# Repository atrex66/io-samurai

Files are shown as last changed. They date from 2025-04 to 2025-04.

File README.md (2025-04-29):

# io-samurai
An open-source, budget-friendly CNC Input Output interface for LinuxCNC, 16 inputs (20–50 V), 8 high-current outputs (50 V, 500 mA Max), and single analog input (0–3.3 V). Supports W5100S-EVB-Pico module. Further support W5500-lite + pico or pico2

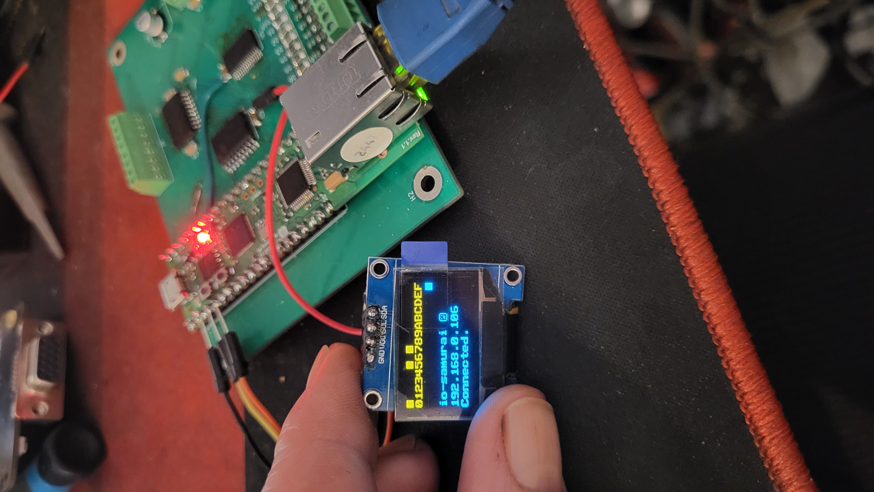
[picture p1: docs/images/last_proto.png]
io-samurai PCB


## Features
- **High-Speed Interface**: W5100S-evb-pico Ethernet. https://docs.wiznet.io/Product/iEthernet/W5100S/w5100s-evb-pico
- **Inputs**: 16 channels (MCP23017, I2C), 20–50 V, with 10 kΩ/1.5 kΩ divider and 3.6 V Zener protection.
- **Outputs**: 8 channels (TD62783 Darlington driver, MCP23008-controlled), 50 V, 500 mA/channel.
- **Analog Inputs**: 1 channels (GP26), 12-bit, ~10 kΩ potentiometer, 100 nF filtering.
- **Display**: Optional SH1106 OLED (128x64) for I/O status and IP address (not required for operation).
- **Software**:
  - LinuxCNC HAL driver, with safety functions (timeout, data checks).
  - Python library for automation/remote I/O.
  - Further Mach3 driver development.
- **Hardware Support**: W5100S-EVB-Pico.
- **Open-Source**: All code, PCB production files, and docs under MIT License.

## Support
- **Notes**: If you want to buy ready to go io-samurai send message to me for options.
- **Patreon**: Join our community at [patreon](https://www.patreon.com/c/user?u=43314769).

## License
This project is licensed under the MIT License. See [LICENSE](LICENSE).
The `ioLibrary_Driver` in `firmware/pico/ioLibrary_Driver.zip` is licensed under the MIT License by Wiznet. See [firmware/pico/ioLibrary_Driver.zip/LICENSE.txt](firmware/pico/ioLibrary_Driver.zip/LICENSE.txt).

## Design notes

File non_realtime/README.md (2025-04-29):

# io-samurai C++ Library

The `io-samurai` library is a C++ implementation for communicating with an IO Samurai device over UDP. It is derived from a LinuxCNC HAL driver and provides a simple interface to control digital outputs, read digital inputs, and process analog inputs. The library is designed for POSIX-compliant systems (e.g., Linux) and uses standard C++11 features.

## Features
- Initialize communication with an IO Samurai device using an IP address and port.
- Set and reset digital outputs (8 outputs, indexed 0–7).
- Read digital inputs (16 inputs, indexed 0–15).
- Read analog input (scaled to a user-defined range, with optional low-pass filter and rounding).
- Control OLED display state (on/off).
- Check connection status.
- Perform UDP send/receive operations in a single `update` call.

## Requirements
- **Compiler**: `g++` (GCC 4.8 or later, supporting C++11).
- **Operating System**: POSIX-compliant system (e.g., Linux, macOS). Windows is not supported without modifications.
- **Libraries**: Standard C++ Library and POSIX socket APIs (included in `libc` on Linux).
- **Jump Table**: A 256-byte checksum lookup table (`jump_table`) is required, provided via a symbolic link to `../firmware/w5100s-evb-pico/inc/jump_table.h`.

## Installation
1. **Clone or Download**: Obtain the source files:
   - `io-samurai.h`
   - `io-samurai.cpp` 
   - `jump_table.h`  (symbolic link, precreated, relative link to the firmware jump_table)
   - `usage_example.cpp` (example usage)

2. **Install Dependencies** (on Ubuntu/Debian):
   ```
   bash
   sudo apt update
   sudo apt install g++ libc6-dev
   ```

## Compilation
Compile the library and example using `g++`:

```
bash
g++ -std=c++11 -o io_samurai io-samurai.cpp main.cpp
```

**Flags**:
- `-std=c++11`: Enables C++11 features.
- `-o io_samurai`: Specifies the output executable name.

If the `jump_table` implementation is in a separate object file (e.g., `jump_table.o`):
```
bash
g++ -std=c++11 -o io_samurai io-samurai.cpp main.cpp jump_table.o
```

Run the program:
```
bash
./io_samurai
```

## Usage
The `io-samurai` class provides a straightforward API for interacting with the device. Below is an example program (`main.cpp`):

```
cpp
#include "io-samurai.h"
#include <iostream>
#include <chrono>
#include <thread>

int main() {
    io-samurai io;

    // Initialize with IP and port
    if (!io.init("192.168.1.100", 8080)) {
        std::cerr << "Initialization failed" << std::endl;
        return 1;
    }

    // Set analog range (e.g., 0 to 10 volts)
    io.set_analog_range(0.0f, 10.0f);
    io.set_analog_lowpass(true);  // Enable low-pass filter
    io.set_analog_rounding(true); // Enable rounding
    io.set_oled_off(false);       // Keep OLED on

    // Main loop
    while (true) {
        // Set outputs
        io.set_output(0, true);  // Set output 0
        io.set_output(1, false); // Clear output 1

        // Perform communication
        io.update();

        // Read inputs
        for (int i = 0; i < 16; i++) {
            std::cout << "Input " << i << ": " << io.get_input(i) << std::endl;
        }

        // Read analog input
        std::cout << "Analog In: " << io.get_analog_in() << std::endl;
        std::cout << "Analog In (s32): " << io.get_analog_in_s32() << std::endl;
        std::cout << "Connected: " << io.is_connected() << std::endl;

        // Sleep for 1 ms
        std::this_thread::sleep_for(std::chrono::milliseconds(1));
    }

    return 0;
}
```

### API Overview
- **Constructor/Destructor**:
  - `io-samurai()`: Initializes the object.
  - `~io-samurai()`: Closes the socket.

- **Initialization**:
  - `bool init(const std::string& ip_address, int port)`: Sets up the UDP socket with the given IP and port. Returns `true` on success.

- **Output Control**:
  - `void set_output(int index, bool value)`: Sets output `index` (0–7) to `value`.
  - `void reset_output(int index)`: Clears output `index` (0–7).

- **Input Reading**:
  - `bool get_input(int index) const`: Returns the state of input `index` (0–15).
  - `float get_analog_in() const`: Returns the scaled analog input value.
  - `int32_t get_analog_in_s32() const`: Returns the analog input as an integer.

- **Analog Configuration**:
  - `void set_analog_range(float min_value, float max_value)`: Sets the analog input range.
  - `void set_analog_lowpass(bool enable)`: Enables/disables the low-pass filter.
  - `void set_analog_rounding(bool enable)`: Enables/disables rounding of analog values.

- **OLED Control**:
  - `void set_oled_off(bool off)`: Turns the OLED display on (`false`) or off (`true`).

- **Connection Status**:
  - `bool is_connected() const`: Returns `true` if the last communication was successful.

- **Communication**:
  - `void update()`: Sends output data and receives input data over UDP.

## Notes
- **Jump Table**: The `jump_table` is provided via a symbolic link to `../firmware/w5100s-evb-pico/inc/jump_table.h`.
- **Timing**: The example uses `std::this_thread::sleep_for` for a 1 ms interval. Adjust the sleep duration as needed for your application.
- **Watchdog and Threading**: The watchdog functionality were removed to simplify the library. The `update` function must be called manually in a loop.
- **Error Handling**: Errors (e.g., socket failures, checksum errors) are logged to `std::cerr`. Check the console output for issues.
- **Platform**: The library uses POSIX socket APIs (`sys/socket.h`, `netinet/in.h`). For Windows, rewrite the socket code using Winsock.

## Troubleshooting
- **Compilation Error: `sockaddr_in` incomplete type**:
  - Ensure `<netinet/in.h>` is included in `io-samurai.h`.
- **Compilation Error: `jump_table` undefined**:
  - Verify the symbolic link to `jump_table.h` is correct and the table is defined or linked.
- **Runtime Error: `Checksum error`**:
  - Ensure the `jump_table` implementation is correct and accessible.
- **Socket Errors**:
  - Verify the IP address and port are correct and the device is reachable.
  - Check for permission issues (e.g., run as root if binding to a low port).
- **Missing Headers**:
  - Install `libc6-dev`:
    ```
    bash
    sudo apt install libc6-dev
    ```

## Contributing
- Report issues or suggest enhancements via email to atrex66@gmail.com

## License
MIT License (based on the original LinuxCNC HAL driver by Viola Zsolt)

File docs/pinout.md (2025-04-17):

# IO-Samurai Pinout

## J1 (input block 0)
- Pin 1: input-00
- Pin 2: input-01
- Pin 3: input-02
- Pin 4: input-03
- Pin 5: input-04
- Pin 6: input-05
- Pin 7: input-06
- Pin 8: input-07

## J2 (input block 1)
- Pin 1: input-08
- Pin 2: input-09
- Pin 3: input-10
- Pin 4: input-11
- Pin 5: input-12
- Pin 6: input-13
- Pin 7: input-14
- Pin 8: input-15

## J3 (output block 0)
- Pin 1: output-00
- Pin 2: output-01
- Pin 3: output-02
- Pin 4: output-03
- Pin 5: output-04
- Pin 6: output-05
- Pin 7: output-06
- Pin 8: output-07

## J4 (24v power)
- Pin 1: GND
- Pin 2: GND
- Pin 3: +24V
- Pin 4: +24V

## J5 (5v power)
- Pin 1: +5V
- Pin 2: GND

## J6 (oled connector)
- Pin 1: GND
- Pin 2: +5V
- Pin 3: sck
- Pin 4: sda

## J7 (Analog input)
- Pin 1: +3.3V
- Pin 2: Analog in
- Pin 3: GND

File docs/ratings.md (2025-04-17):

# io-samurai Ratings

## 1.Power (5v)
- **Connector**: 2-pin header (J5)
- **Notes**: Connects to the Vsys pin trough schottky diode

## 2.Power (20v - 50v)
- **Connector**: 4-pin header (J4)
- **Notes**: Powering the TD62783

## Inputs (16)
- **IC**: MCP23017 (I2C, 3.3 V V_DD, GPA0–GPA7, GPB0–GPB7).
- **Connector**: 2x8-pin header.
- **Protection**: 10 kΩ/1.5 kΩ voltage divider, 3.6 V Zener diode (SOD523).
- **Ratings**:
  - **Min. Input Voltage**: 20.25 V (for high logic level, ≥ 2.64 V on MCP23017).
  - **Max. Input Voltage**: 50 V (Zener limits to 3.6 V).
  - **Max. Input Current**: ~2.04 mA (24 V input).
  - **Logic Levels**: High ≥ 2.64 V, Low ≤ 0.66 V (3.3 V V_DD).
  - **Power Dissipation**:
    - R1 (10 kΩ): ~41.6 mW (24 V).
    - R2 (1.5 kΩ): ~8.64 mW.
    - Zener: ~7.34 mW (24 V).
- **Notes**: Designed for 20–50 V signals.

## Outputs (8)
- **IC**: TD62783 (8-channel Darlington driver), driven by MCP23008 (I2C, 3.3 V).
- **Connector**: 8-pin header.
- **Ratings**:
  - **Input Voltage**: 3.3 V (MCP23008 GPIO, high ≥ 2.0 V, low ≤ 0.8 V).
  - **Max. Output Voltage**: 50 V (open collector).
  - **Max. Output Current**: 500 mA/channel, ~1.5 A total (cooling required).
  - **Typical Load**: 5–24 V, 50–200 mA/channel (relays, LEDs).
  - **Power Dissipation**: Max. 1.47 W (25°C, DIP-18).
- **Notes**: Use flyback diodes (e.g., 1N4007) for inductive loads.

## Analog Inputs (1)
- **Pins**: GP26 (ADC0).
- **Connector**: 3-pin header (VCC, GND, signal).
- **Protection/Filtering**: 100 nF capacitor, 10 kΩ pull-down.
- **Potentiometer**:
  - **Recommended Value**: 10 kΩ (linear, B10K).
  - **Range**: 0–3.3 V.
  - **Time Constant**: ~0.5 ms (with 100 nF capacitor).
  - **Power Consumption**: ~1 mW (3.3 V).
  - **Alternatives**: 4.7 kΩ (faster, ~2 mW), 22 kΩ (slower, ~0.5 mW).
- **Ratings**:
  - **Input Voltage**: 0–3.3 V.
  - **Resolution**: 12-bit (0–4095).

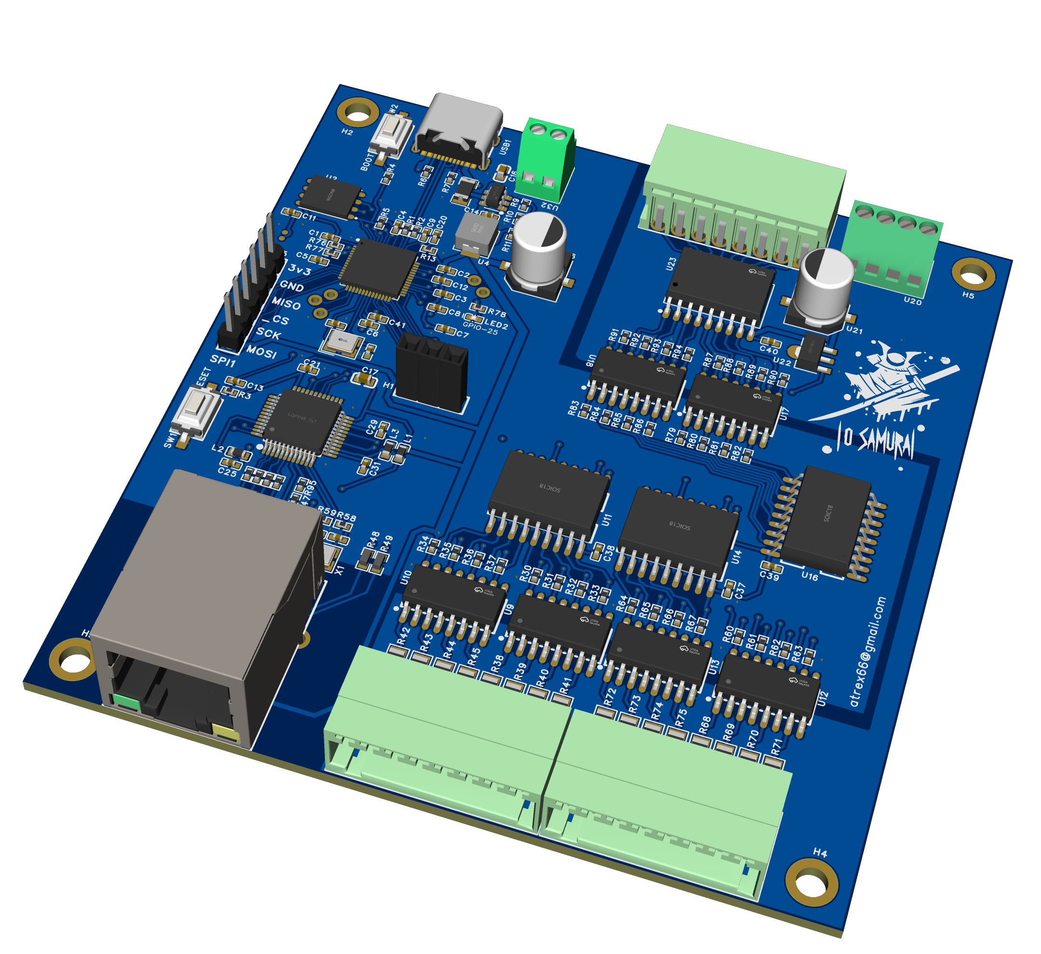
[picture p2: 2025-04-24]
docs/images/io-samurai-v2_3d.png

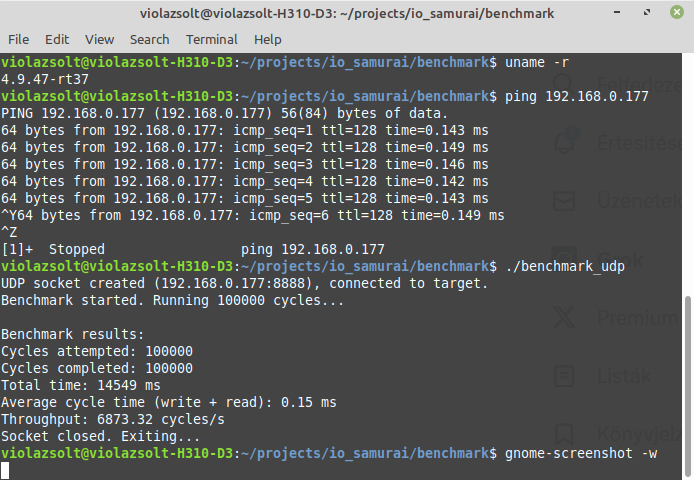
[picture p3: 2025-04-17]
docs/images/Screenshot from 2025-03-26 13-51-27.png

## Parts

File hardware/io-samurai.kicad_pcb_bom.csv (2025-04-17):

Designator | Quantity | Value | Footprint | Package | MPN | DNP | Mount_Type | Description
A1 | 1 | RaspberryPi_Pico | RaspberryPi_Pico_Common_THT |  |  |  | tht | Versatile and inexpensive wireless microcontroller module powered by RP2040 dual-core Arm Cortex-M0+ processor up to 133 MHz, 264kB SRAM, 2MB QSPI flash, Infineon CYW43439 2.4GHz 802.11n wireless LAN; also supports Raspberry Pi Pico 2 W
C1, C10, C2, C3, C5, C7, C9 | 7 | 100nF | C_1206_3216Metric |  |  |  | smt | Unpolarized capacitor
C6 | 1 | 100uF 9v | CP_Elec_8x5.4 |  |  |  | smt | Polarized capacitor
C8 | 1 | 100uF 50v | CP_Elec_8x5.4 |  |  |  | smt | Polarized capacitor
D1, D10, D11, D12, D13, D14, D15, D16, D2, D3, D4, D5, D6, D7, D8, D9 | 16 | 3v6 | D_SOD-523 |  |  |  | smt | Zener diode
D17 | 1 | D_Schottky | D_SOD-523 |  |  |  | smt | Schottky diode
J1, J2, J3 | 3 | Screw_Terminal_01x08 | TerminalBlock_Xinya_XY308-2.54-8P_1x08_P2.54mm_Horizontal |  |  |  | tht | Generic screw terminal, single row, 01x08, script generated (kicad-library-utils/schlib/autogen/connector/)
J4 | 1 | Screw_Terminal_01x04 | TerminalBlock_Xinya_XY308-2.54-4P_1x04_P2.54mm_Horizontal |  |  |  | tht | Generic screw terminal, single row, 01x04, script generated (kicad-library-utils/schlib/autogen/connector/)
J5 | 1 | Screw_Terminal_01x02 | TerminalBlock_Xinya_XY308-2.54-2P_1x02_P2.54mm_Horizontal |  |  |  | tht | Generic screw terminal, single row, 01x02, script generated (kicad-library-utils/schlib/autogen/connector/)
J6 | 1 | Conn_01x04_Pin | PinHeader_1x04_P2.54mm_Vertical |  |  |  | tht | Generic connector, single row, 01x04, script generated
J7 | 1 | Screw_Terminal_01x03 | TerminalBlock_Xinya_XY308-2.54-3P_1x03_P2.54mm_Horizontal |  |  |  | tht | Generic screw terminal, single row, 01x03, script generated (kicad-library-utils/schlib/autogen/connector/)
J8, J9 | 2 | Conn_01x06_Pin | PinHeader_1x06_P2.54mm_Vertical |  |  |  | tht | Generic connector, single row, 01x06, script generated
JP1 | 1 | Jumper_2_Open | SolderJumper-2_P1.3mm_Open_TrianglePad1.0x1.5mm |  |  |  | tht | Jumper, 2-pole, open
R1, R10, R11, R12, R13, R14, R15, R16, R2, R3, R36, R4, R5, R6, R7, R8, R9 | 17 | 10k | R_0805_2012Metric |  |  |  | smt | Resistor
R17, R18 | 2 | 4k7 | R_0805_2012Metric |  |  |  | smt | Resistor
R19 | 1 | 100k | R_0805_2012Metric |  |  |  | smt | Resistor
R20, R21, R22, R23, R24, R25, R26, R27, R28, R29, R30, R31, R32, R33, R34, R35 | 16 | 1.5k | R_0805_2012Metric |  |  |  | smt | Resistor
U1 | 1 | MCP23017_SS | SSOP-28_5.3x10.2mm_P0.65mm |  |  |  | smt | 16-bit I/O expander, I2C, interrupts, w pull-ups, SSOP-28
U2 | 1 | MCP23008-xSO | SOIC-18W_7.5x11.6mm_P1.27mm |  |  |  | smt | 8-bit I/O expander, I2C, interrupts, SOIC-18
U3 | 1 | TBD62783A | SOIC-18W_7.5x11.6mm_P1.27mm |  |  |  | smt | 8-Channel Source Type Transistor Array, TTL and CMOS compatible, 500mA, 50V, DIP-18/SOP-18/SSOP-18/SOIC-18W

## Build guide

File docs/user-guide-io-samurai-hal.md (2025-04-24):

# HAL User Guide for `io-samurai` Component

The `io-samurai` component is a Hardware Abstraction Layer (HAL) driver for the io-samurai, designed for LinuxCNC. It communicates with the io-samurai over UDP to handle digital and analog inputs/outputs. This guide explains the component's pins, parameters, and their roles.

## Overview

The `io-samurai` component:
- Communicates via UDP with multiple io-samurai with configurable IP address and port (loadrt io-samurai ip_address="192.168.0.177:8888;192.168.0.178:8889").
- Supports 16 digital inputs, 8 digital outputs, and 1 analog input per card.
- Includes a watchdog mechanism to detect communication timeouts both the driver and io-samurai side.
- Provides low-pass filtering and scaling for the analog input.
- Integrates with LinuxCNC's HAL for real-time I/O processing.

## HAL Pins

### Digital Inputs
- **Pin Names**: `io-samurai.input-00` to `io-samurai.input-15` (HAL_OUT, bit)
- **Description**: These 16 pins represent the state of digital inputs received from the remote device (0 or 1). Each pin corresponds to one bit in the received UDP packet.
- **Negated Inputs**: `io-samurai.input-00-not` to `io-samurai.input-15-not` (HAL_OUT, bit)
  - These pins provide the logical negation of the corresponding input pins (e.g., `input-00-not` is the inverse of `input-00`).

### Digital Outputs
- **Pin Names**: `io-samurai.output-00` to `io-samurai.output-07` (HAL_IN, bit)
- **Description**: These 8 pins control the digital outputs sent to the remote device. Setting a pin to 1 or 0 determines the state of the corresponding output bit in the UDP packet.

### Analog Input
- **Pin Name**: `io-samurai.analog-in` (HAL_OUT, float)
- **Description**: Represents the scaled and filtered analog input value from the remote device, derived from a 12-bit ADC (0–4095 range). The value is processed with a low-pass filter (EMA, alpha = 0.1) and scaled using the `analog-scale` parameter.
- **Pin Name**: `io-samurai.analog-in-s32` (HAL_OUT, s32)
  - **Description**: Provides the same analog input value as `analog-in`, but cast to a 32-bit integer. This is useful for applications requiring integer values or for overriding floating-point behavior in certain LinuxCNC configurations.

### Analog Parameters
- **Pin Name**: `io-samurai.analog-min` (HAL_IN, float)
  - **Description**: Defines the minimum value for the analog input.
  - **Example**: If `analog-min` is set to -5.0, when the ADC value on the io-samurai reaches 0 the analog-in value in the driver side is set to -5.0.
- **Pin Name**: `io-samurai.analog-max` (HAL_IN, float)
  - **Description**: Defines the maximum value for the analog input.
  - **Example**: Same like the `analog-min` but for the positive side
- **Full Example**: If you want the `analog-in` in 0-10000 range set the `analog-min` to 0 and the `analog-max` to 10000

- **Pin Name**: `io-samurai.analog-rounding` (HAL_IN, bit)
  - **Description**: Controls whether the scaled analog input value is rounded to the nearest integer before being assigned to `analog-in` and `analog-in-s32`. If set to 1, rounding is enabled; if 0, the value remains a floating-point number. Default is 0 (no rounding).
  - **Use Case**: Rounding is useful when precise integer values are needed for control logic or to avoid floating-point precision issues.

### Connection and Status Pins
- **Pin Name**: `io-samurai.connected` (HAL_IN, bit)
  - **Description**: Indicates the connection status with the remote device. Set to 1 when valid UDP packets with correct checksums are received; otherwise, set to 0.
- **Pin Name**: `io-samurai.io-ready-in` (HAL_IN, bit)
  - **Description**: An input pin that signals the readiness of the I/O system from the LinuxCNC side. It is typically set by the control system to indicate that it is ready to process I/O data.
- **Pin Name**: `io-samurai.io-ready-out` (HAL_OUT, bit)
  - **Description**: Reflects the overall readiness of the I/O system. It is set to the value of `io-ready-in` when communication is active and the watchdog has not timed out; otherwise, it is set to 0.

## Functions
The component exports three HAL functions that run periodically:
1. **io-samurai.watchdog-process**: Monitors communication timeouts (100 ms). If no valid packets are received within this period, it sets `watchdog_expired` and logs an error.
2. **io-samurai.udp-io-process-recv**: Handles incoming UDP packets, updates input pins, and processes the analog input.
3. **io-samurai.udp-io-process-send**: Sends output data to the remote device based on the state of output pins.

## Parameters
- **ip_address**: A module parameter (array of strings) specifying the IP address of the remote device. Configured via `RTAPI_MP_ARRAY_STRING`.
  - **Example**: `ip_address=192.168.1.100`

## Usage Notes
1. **Setup**: Load the component in LinuxCNC with the appropriate IP address (e.g., `loadrt io-samurai ip_address=192.168.1.100`).
2. **Analog Input Tuning**:
   - Adjust `analog-scale` to match the desired output range (e.g., 0–10 V).
   - Enable `analog-rounding` if integer values are required.
   - Use `analog-in-s32` for applications needing integer overrides or compatibility with certain LinuxCNC components.
3. **Watchdog**: If a watchdog timeout occurs, the component logs an error and requires a LinuxCNC restart. Monitor the `connected` pin to detect communication issues.
4. **Real-Time Constraints**: Ensure the component runs in a real-time thread to maintain low-latency I/O processing.

## Example HAL Configuration
```hal
# load the io-samurai component
loadrt io-samurai ip_address="192.168.0.177"

# add the output handling process to servo-thread
addf io-samurai.udp-io-process-send servo-thread
# add the output handling process to servo-thread
addf io-samurai.udp-io-process-recv servo-thread
# add watchdog process to the servo-thread
addf io-samurai.watchdog-process servo-thread

# unlink estop loopback
unlinkp iocontrol.0.user-enable-out
unlinkp iocontrol.0.emc-enable-in

# add the io-samurai safety function to the estop-loop
net estop-loop-in iocontrol.0.user-enable-out io-samurai.io-ready-in
net estop-loop-out iocontrol.0.emc-enable-in io-samurai.io-ready-out

# ANALOG feed and rapid override with 5% steps
setp io-samurai.analog-scale 24
setp io-samurai.analog-rounding 1
setp halui.feed-override.direct-value 1
setp halui.rapid-override.direct-value 1
setp halui.feed-override.scale 0.05
setp halui.rapid-override.scale 0.05
net jog-speed halui.feed-override.counts halui.rapid-override.counts io-samurai.analog-in-s32

```

## Error Handling
- **Checksum Errors**: Invalid UDP packet checksums are logged, and `connected` is set to 0.
- **Watchdog Timeout**: If no valid packets are received within 100 ms, `watchdog_expired` is set, and `io-ready-out` is cleared.
- **Socket Errors**: Socket initialization or binding failures are logged, and the component exits with an error.

## Notes on `analog-in-s32`
The `analog-in-s32` pin exists to support scenarios where LinuxCNC components require integer inputs or where floating-point values need to be overridden for compatibility. For example, some motion control modules may expect integer ADC values, and `analog-in-s32` provides a direct way to supply these without additional conversion.

## License
The `io-samurai` component is licensed under the MIT license.

---

This guide provides a concise overview of the `io-samurai` component's functionality and configuration. For advanced usage, refer to the source code or LinuxCNC documentation.

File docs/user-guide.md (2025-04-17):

# io-samurai Setup Guide

This guide explains how to set up the `io-samurai` project for LinuxCNC. It assumes you have a Linux system (e.g., Ubuntu, Debian) with LinuxCNC uspace installed and an `io-samurai` board (W5100S-EVB-Pico prototype or W5500-Lite final PCB).

## Prerequisites
- LinuxCNC (`sudo apt install linuxcnc-uspace`).
- Git (`sudo apt install git`).
- Minicom (`sudo apt install minicom`).
- `io-samurai` hardware (W5100S-EVB-Pico or W5500-Lite PCB with MCP23017, MCP23008, TD62783, 10 kΩ potentiometer).
- USB cable for Pico/Pico 2.

## 0.
- **Connect the io-samurai to the local network (RJ45 cable)**

## 1.
- **Clone the Repository**:
  ```bash
  git clone https://github.com/atrex66/io-samurai.git
  cd io-samurai
  ```

## 2.
- **Install hal driver**:
   ```bash
   cd hal-driver
   chmod +x install.sh
   ./install.sh
   ```

## 3.
- **Install miniterm**:
   ```bash
   sudo apt update
   sudo apt install miniterm
   ```

## 4.
- **(disconnect other pico-s if any) -> Connect the io-samurai card to the PC via USB cable**

## 5.
- **Start miniterm**:
  ```bash
  cd ..
  cd firmware/pico/
  chmod +x sterminal.sh
  ./sterminal.sh
  ```

## 6.
- **Set the IP address for io-samurai in the terminal window**:
  - Default ip:192.168.0.177
  - "ip ###.###.###.###" + Enter
- **When the io-samurai restarting you succesfully set the ip address**
- **Disconnect the io-samurai from the USB (unplug) -> close the terminal window**

## 7.
- **Copy the io-samurai.hal file to the linuxcnc/configs/{your_machine} directory**
  - add the following line to your {your_machine}.hal file
  - source io-samurai.hal

## 8.
- **Change the ip address to the set io-samurai ip address in the io-samurai.hal first line**

## 9.
- **Start your linuxcnc machine**
  - check the usable hal pins in 'halshow' like io-samurai.input-00 and io-samurai.output-00

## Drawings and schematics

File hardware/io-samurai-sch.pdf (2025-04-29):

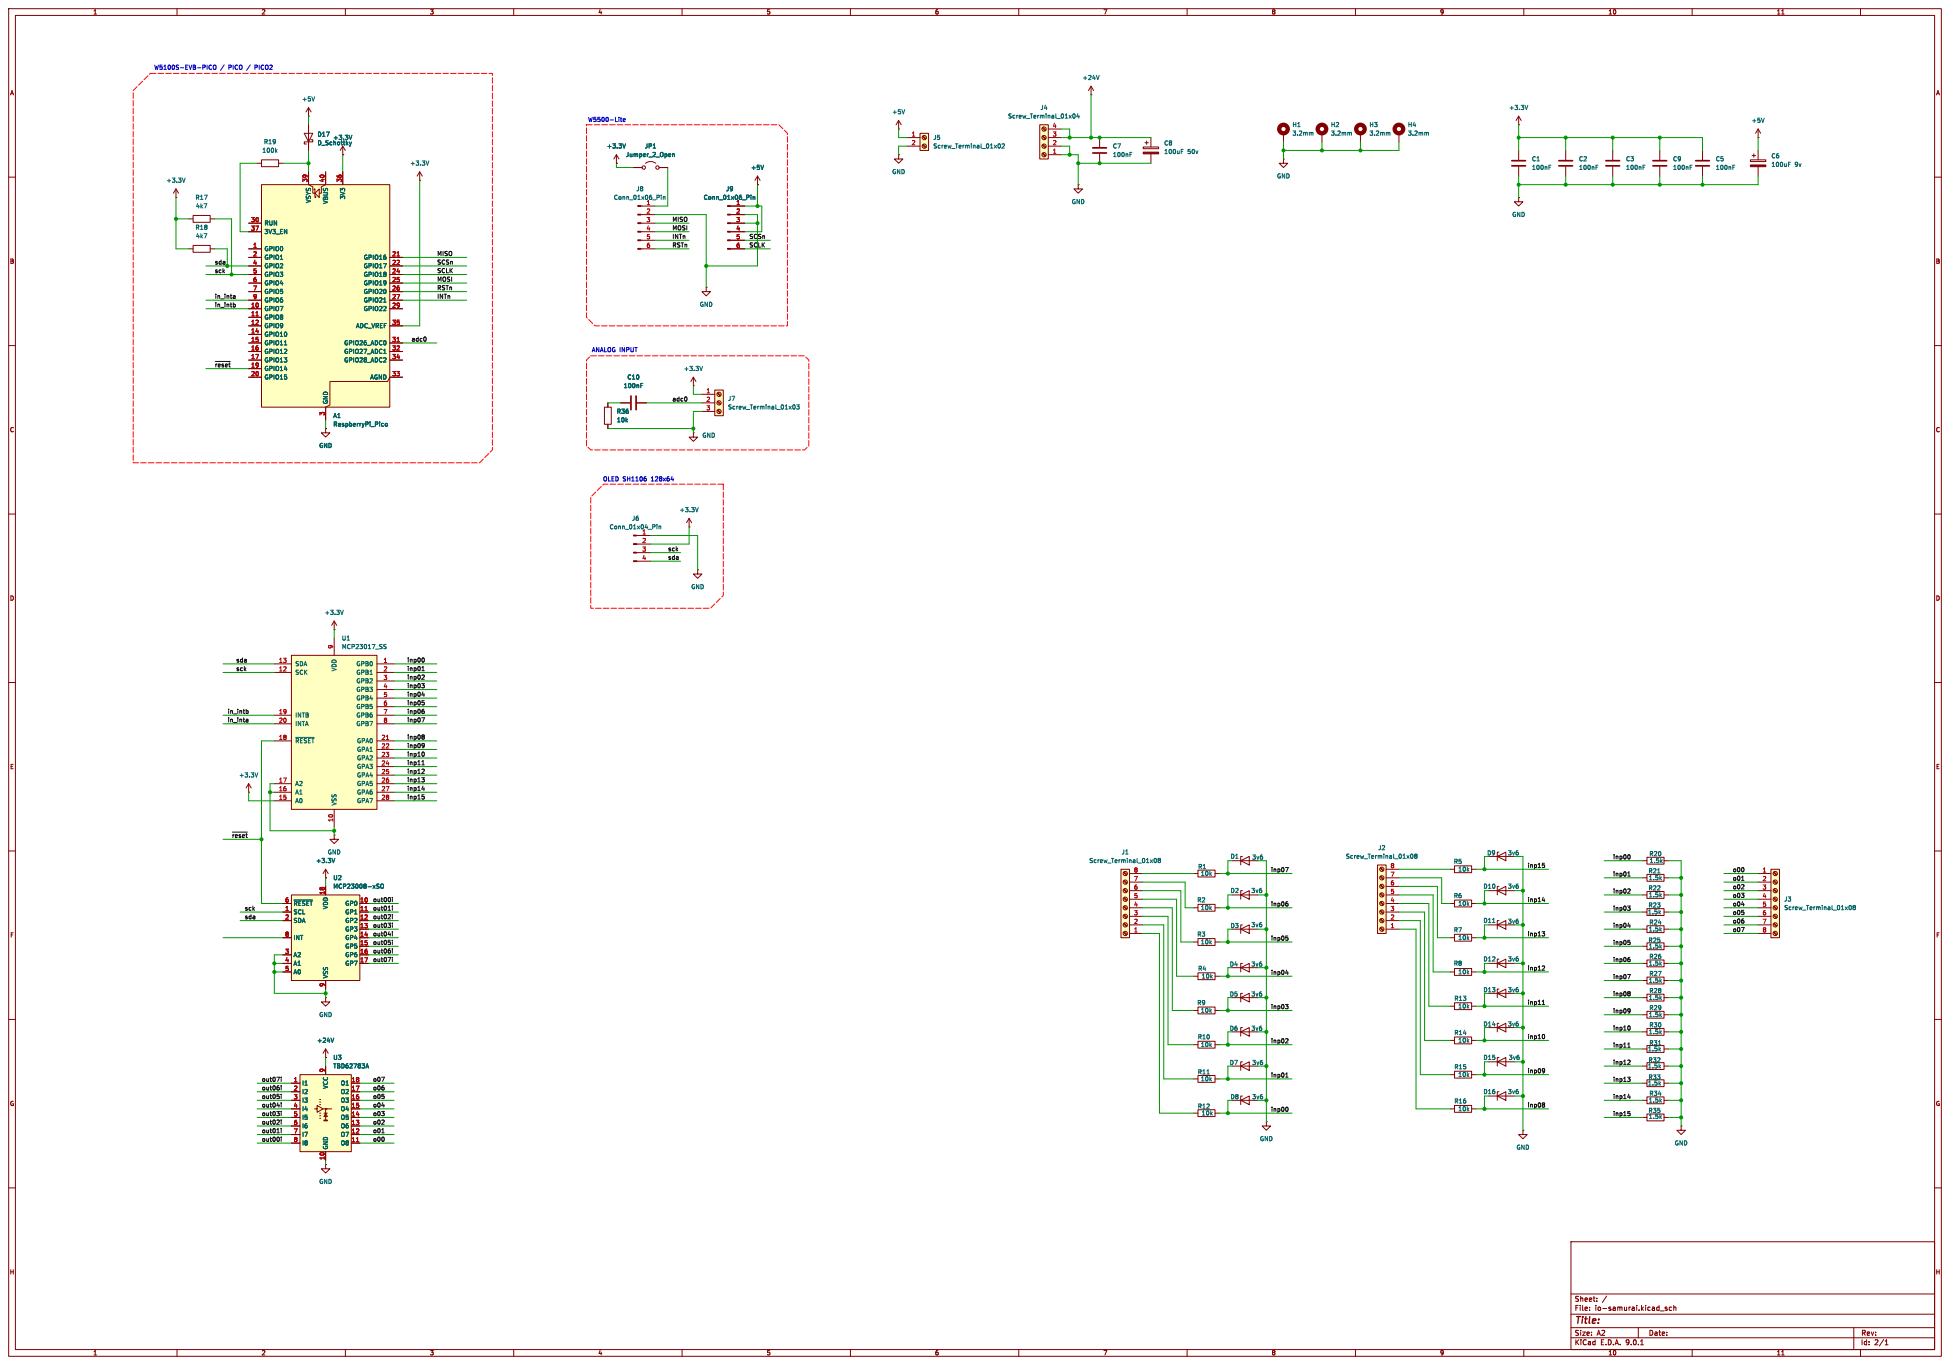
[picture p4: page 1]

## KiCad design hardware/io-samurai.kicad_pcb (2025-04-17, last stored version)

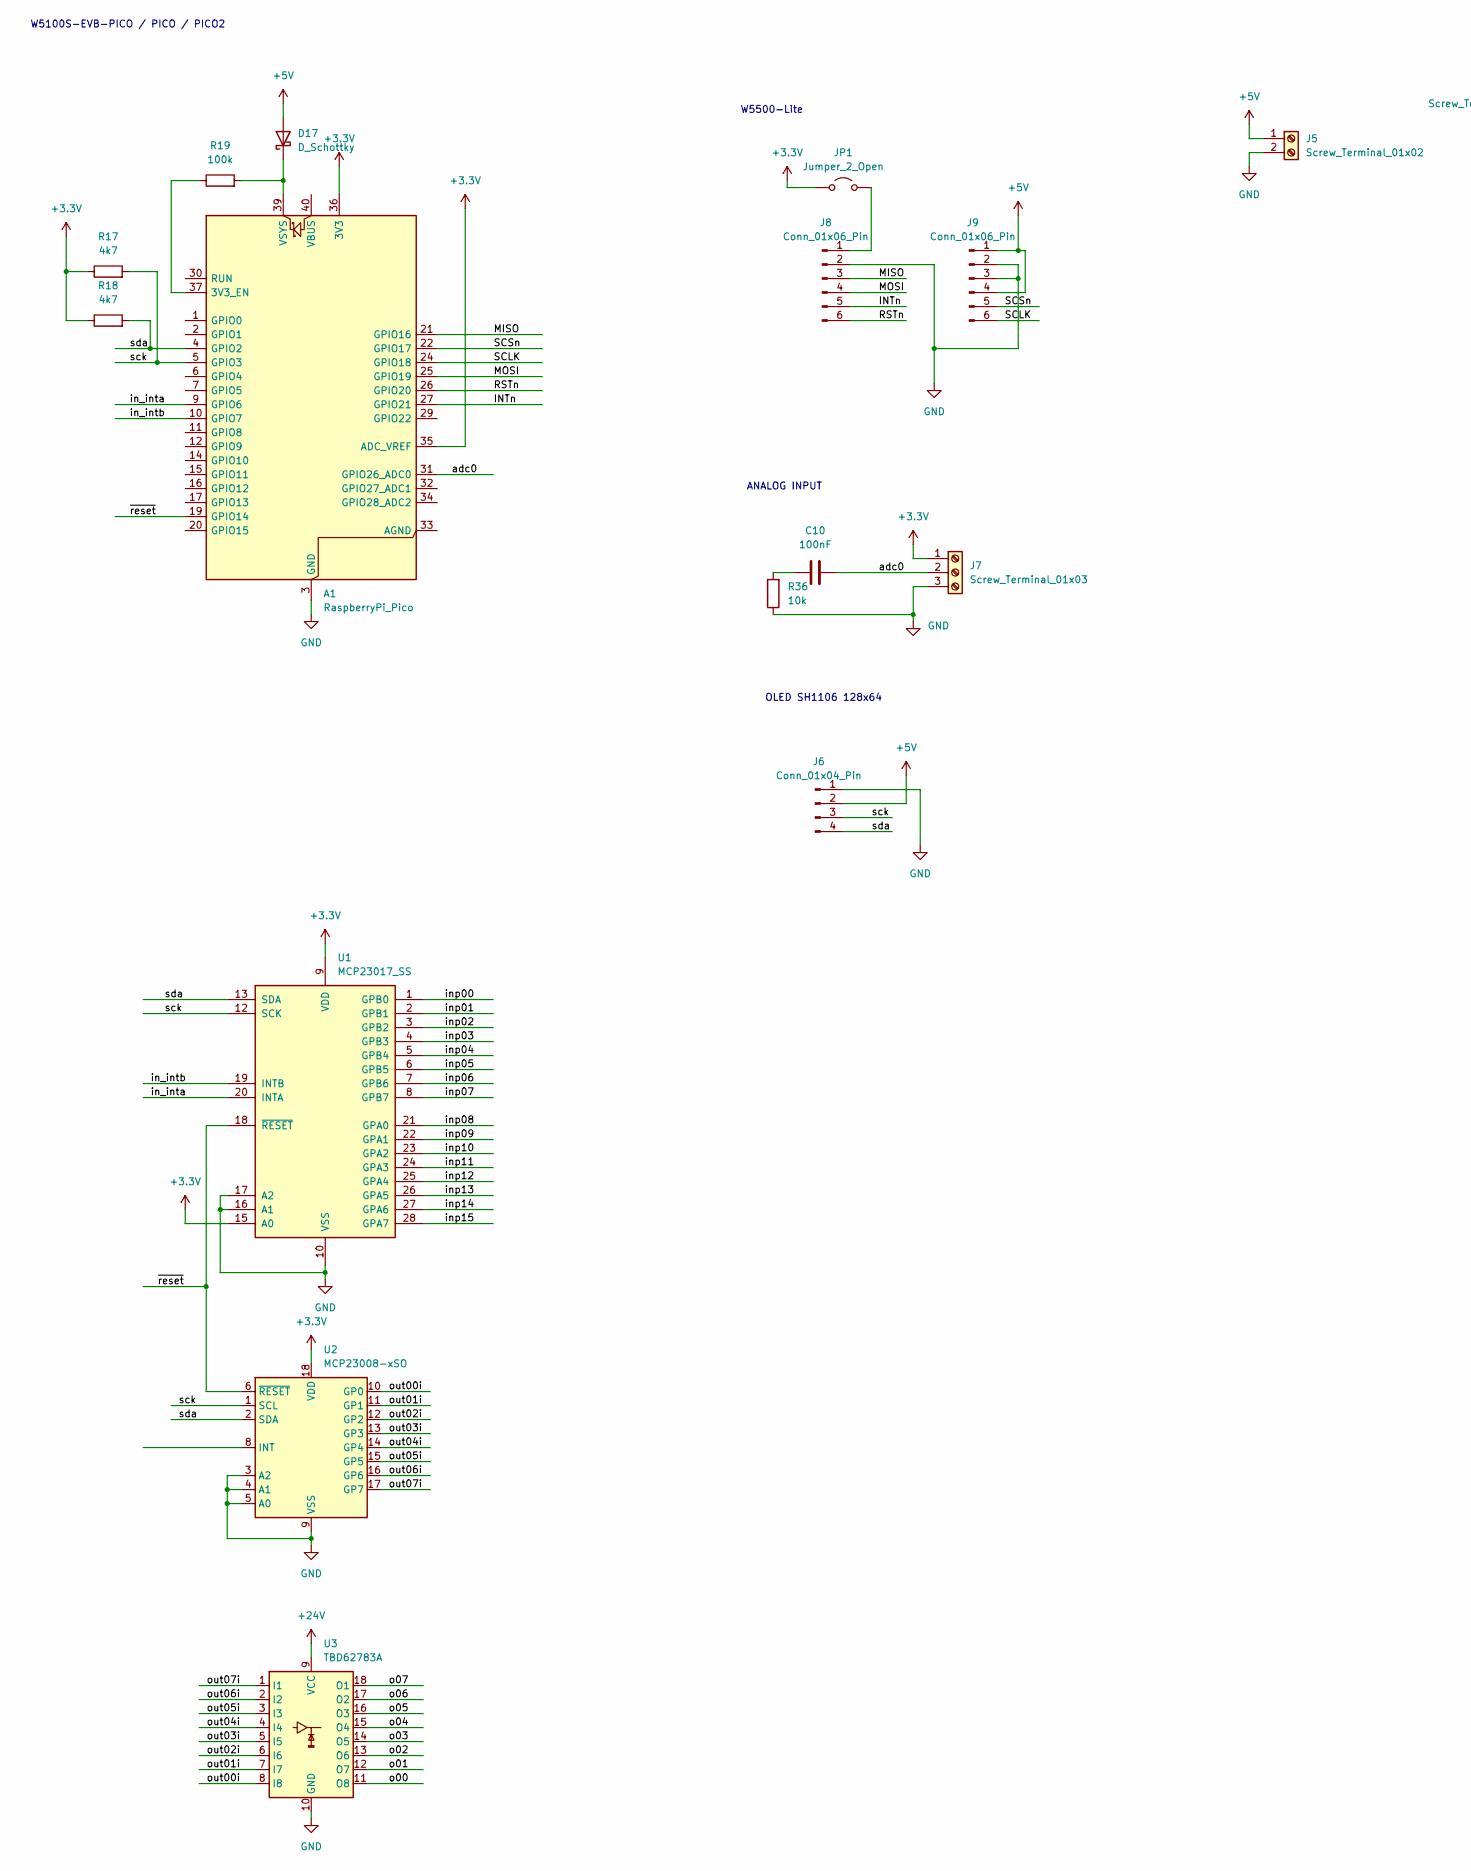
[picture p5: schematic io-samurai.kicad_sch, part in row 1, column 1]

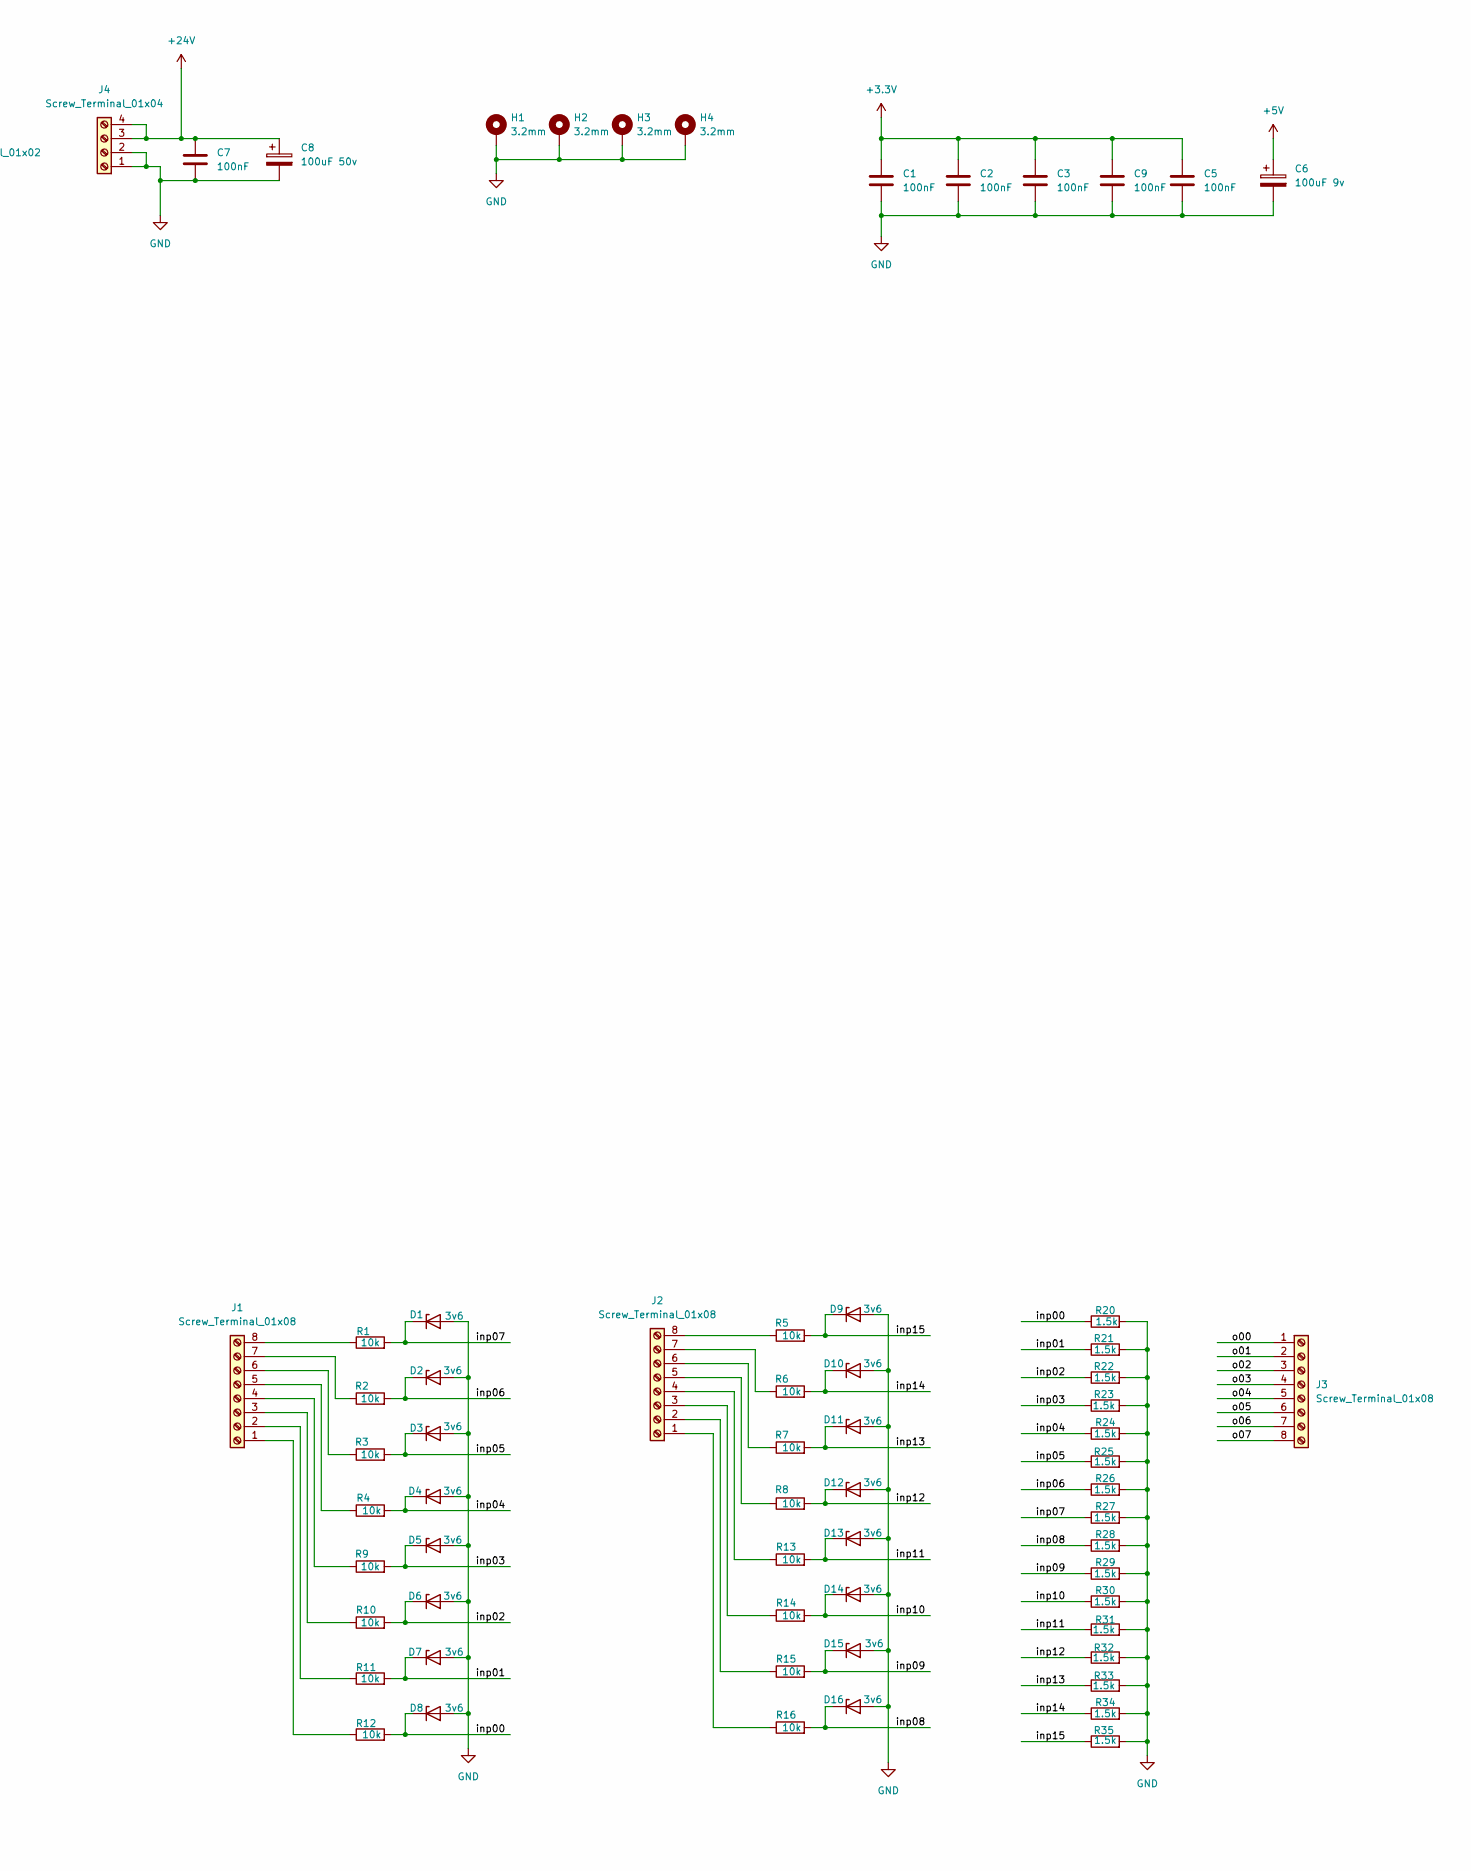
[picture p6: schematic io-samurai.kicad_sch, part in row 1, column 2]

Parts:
A1: RaspberryPi_Pico; RaspberryPi_Pico_Common_THT
C1, C2, C3, C5, C7, C9, C10: 100nF; C_1206_3216Metric
C6: 100uF 9v; CP_Elec_8x5.4
C8: 100uF 50v; CP_Elec_8x5.4
D1, D2, D3, D4, D5, D6, D7, D8, D9, D10, D11, D12, D13, D14, D15, D16: 3v6; D_SOD-523
D17: D_Schottky; D_SOD-523
H1, H2, H3, H4: 3.2mm; MountingHole_3.2mm_M3_Pad_TopBottom
J1, J2, J3: Screw_Terminal_01x08; TerminalBlock_Xinya_XY308-2.54-8P_1x08_P2.54mm_Horizontal
J4: Screw_Terminal_01x04; TerminalBlock_Xinya_XY308-2.54-4P_1x04_P2.54mm_Horizontal
J5: Screw_Terminal_01x02; TerminalBlock_Xinya_XY308-2.54-2P_1x02_P2.54mm_Horizontal
J6: Conn_01x04_Pin; PinHeader_1x04_P2.54mm_Vertical
J7: Screw_Terminal_01x03; TerminalBlock_Xinya_XY308-2.54-3P_1x03_P2.54mm_Horizontal
J8, J9: Conn_01x06_Pin; PinHeader_1x06_P2.54mm_Vertical
JP1: Jumper_2_Open; SolderJumper-2_P1.3mm_Open_TrianglePad1.0x1.5mm
R1, R2, R3, R4, R5, R6, R7, R8, R9, R10, R11, R12, R13, R14, R15, R16, R36: 10k; R_0805_2012Metric
R17, R18: 4k7; R_0805_2012Metric
R19: 100k; R_0805_2012Metric
R20, R21, R22, R23, R24, R25, R26, R27, R28, R29, R30, R31, R32, R33, R34, R35: 1.5k; R_0805_2012Metric
U1: MCP23017_SS; SSOP-28_5.3x10.2mm_P0.65mm
U2: MCP23008-xSO; SOIC-18W_7.5x11.6mm_P1.27mm
U3: TBD62783A; SOIC-18W_7.5x11.6mm_P1.27mm

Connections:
+3.3V: A1.35 (ADC_VREF), A1.36 (3V3), C1.1, C2.1, C3.1, C5.1, C9.1, J7.1, JP1.1 (A), R17.1, R18.1, U1.9 (VDD), U1.15 (A0), U2.18 (VDD)
+5V: C6.1, D17.2 (A), J5.1, J6.2, J9.1, J9.4
+24V: C7.1, C8.1, J4.3, J4.4, U3.9 (VCC)
/INTn: A1.27 (GPIO21), J8.5
/MISO: A1.21 (GPIO16), J8.3
/MOSI: A1.25 (GPIO19), J8.4
/RSTn: A1.26 (GPIO20), J8.6
/SCLK: A1.24 (GPIO18), J9.6
/SCSn: A1.22 (GPIO17), J9.5
/adc0: A1.31 (GPIO26_ADC0), C10.1, J7.2
/in_inta: A1.9 (GPIO6), U1.20 (INTA)
/in_intb: A1.10 (GPIO7), U1.19 (INTB)
/inp00: D8.1 (K), R12.2, R20.1, U1.1 (GPB0)
/inp01: D7.1 (K), R11.2, R21.1, U1.2 (GPB1)
/inp02: D6.1 (K), R10.2, R22.1, U1.3 (GPB2)
/inp03: D5.1 (K), R9.2, R23.1, U1.4 (GPB3)
/inp04: D4.1 (K), R4.2, R24.1, U1.5 (GPB4)
/inp05: D3.1 (K), R3.2, R25.1, U1.6 (GPB5)
/inp06: D2.1 (K), R2.2, R26.1, U1.7 (GPB6)
/inp07: D1.1 (K), R1.2, R27.1, U1.8 (GPB7)
/inp08: D16.1 (K), R16.2, R28.1, U1.21 (GPA0)
/inp09: D15.1 (K), R15.2, R29.1, U1.22 (GPA1)
/inp10: D14.1 (K), R14.2, R30.1, U1.23 (GPA2)
/inp11: D13.1 (K), R13.2, R31.1, U1.24 (GPA3)
/inp12: D12.1 (K), R8.2, R32.1, U1.25 (GPA4)
/inp13: D11.1 (K), R7.2, R33.1, U1.26 (GPA5)
/inp14: D10.1 (K), R6.2, R34.1, U1.27 (GPA6)
/inp15: D9.1 (K), R5.2, R35.1, U1.28 (GPA7)
/o00: J3.1, U3.11 (O8)
/o01: J3.2, U3.12 (O7)
/o02: J3.3, U3.13 (O6)
/o03: J3.4, U3.14 (O5)
/o04: J3.5, U3.15 (O4)
/o05: J3.6, U3.16 (O3)
/o06: J3.7, U3.17 (O2)
/o07: J3.8, U3.18 (O1)
/out00i: U2.10 (GP0), U3.8 (I8)
/out01i: U2.11 (GP1), U3.7 (I7)
/out02i: U2.12 (GP2), U3.6 (I6)
/out03i: U2.13 (GP3), U3.5 (I5)
/out04i: U2.14 (GP4), U3.4 (I4)
/out05i: U2.15 (GP5), U3.3 (I3)
/out06i: U2.16 (GP6), U3.2 (I2)
/out07i: U2.17 (GP7), U3.1 (I1)
/sck: A1.5 (GPIO3), J6.3, R17.2, U1.12 (SCK), U2.1 (SCL)
/sda: A1.4 (GPIO2), J6.4, R18.2, U1.13 (SDA), U2.2 (SDA)
/~reset: A1.19 (GPIO14), U1.18 (~RESET), U2.6 (~RESET)
GND: A1.3 (GND), A1.8 (GND), A1.13 (GND), A1.18 (GND), A1.23 (GND), A1.28 (GND), A1.38 (GND), C1.2, C2.2, C3.2, C5.2, C6.2, C7.2, C8.2, C9.2, D1.2 (A), D2.2 (A), D3.2 (A), D4.2 (A), D5.2 (A), D6.2 (A), D7.2 (A), D8.2 (A), D9.2 (A), D10.2 (A), D11.2 (A), D12.2 (A), D13.2 (A), D14.2 (A), D15.2 (A), D16.2 (A), H1.1, H2.1, H3.1, H4.1, J4.1, J4.2, J5.2, J6.1, J7.3, J8.2, J9.2, J9.3, R20.2, R21.2, R22.2, R23.2, R24.2, R25.2, R26.2, R27.2, R28.2, R29.2, R30.2, R31.2, R32.2, R33.2, R34.2, R35.2, R36.1, U1.10 (VSS), U1.16 (A1), U1.17 (A2), U2.3 (A2), U2.4 (A1), U2.5 (A0), U2.9 (VSS), U3.10 (GND)
unnamed: A1.37 (3V3_EN), R19.1
unnamed: A1.39 (VSYS), D17.1 (K), R19.2
unnamed: C10.2, R36.2
unnamed: J1.1, R12.1
unnamed: J1.2, R11.1
unnamed: J1.3, R10.1
unnamed: J1.4, R9.1
unnamed: J1.5, R4.1
unnamed: J1.6, R3.1
unnamed: J1.7, R2.1
unnamed: J1.8, R1.1
unnamed: J2.1, R16.1
unnamed: J2.2, R15.1
unnamed: J2.3, R14.1
unnamed: J2.4, R13.1
unnamed: J2.5, R8.1
unnamed: J2.6, R7.1
unnamed: J2.7, R6.1
unnamed: J2.8, R5.1
unnamed: J8.1, JP1.2 (B)

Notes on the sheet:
W5500-Lite
OLED SH1106 128x64
ANALOG INPUT
W5100S-EVB-PICO / PICO / PICO2

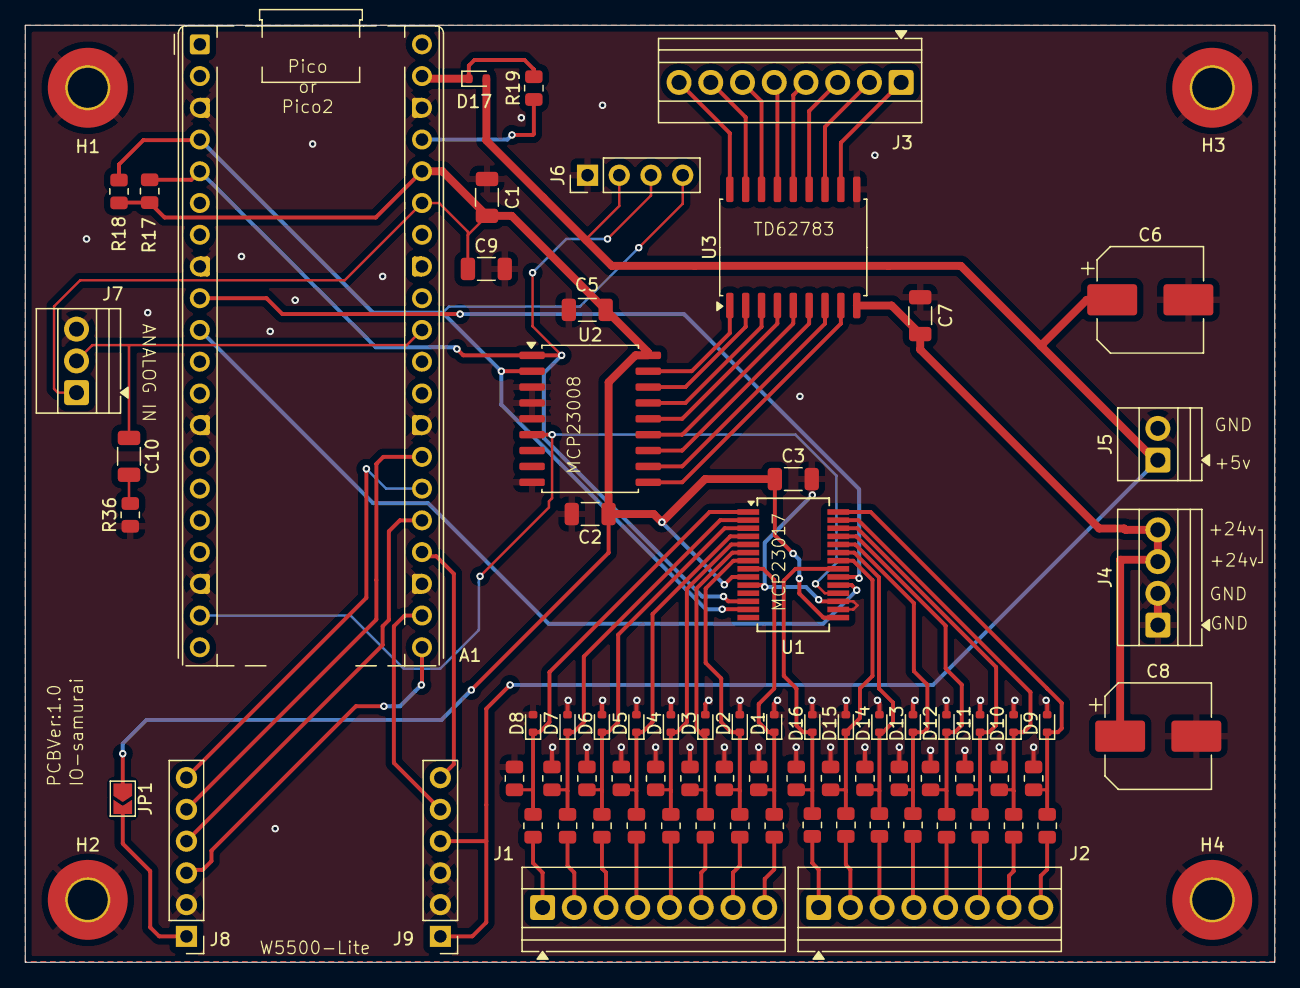
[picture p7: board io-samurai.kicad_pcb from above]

Board: 2 copper layers, 100.0 x 75.0 mm, 80 parts (0 on the bottom side), 68 nets.

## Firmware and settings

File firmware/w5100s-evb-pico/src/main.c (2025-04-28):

#include <stdio.h>
#include <string.h>
#include <stdlib.h>
#include "pico/stdlib.h"
#include "pico/stdio_usb.h"
#include "pico/multicore.h"
#include "hardware/spi.h"
#include "hardware/dma.h"
#include "hardware/gpio.h"
#include "hardware/i2c.h"
#include "hardware/adc.h"
#include "hardware/watchdog.h"
#include "hardware/clocks.h"
#include "serial_terminal.h"
#include "wizchip_conf.h"
#include "socket.h"
#include "sh1106.h"
#include "jump_table.h"
#include "main.h"
#include "config.h"

// Author:Viola Zsolt (atrex66@gmail.com)
// Date: 2025
// Description: IO-Samurai V1.0 driver for Raspberry Pi Pico + W5100S (W5100S-EVB-PICO)
// License: MIT
// Description: This code is a driver for the IO-Samurai V1.0 board, which uses a Raspberry Pi Pico and a W5100S Ethernet chip.
// It also includes a serial terminal interface for configuration and debugging.
// The code is designed to run on the Raspberry Pi Pico and uses the Pico SDK for hardware access.
// The code is structured to run on two cores, with core 0 handling network communication and core 1 handling GPIO, ADC, Oled and terminal config.
// The code is using DMA for SPI (burst) communication with the W5100S chip, which allows for high-speed data transfer.
// do not chase errors in the local network when the W5100S only run in 10Mbit/s mode, it's not necessary higher data rate, the driver capable over 6000 reads+writes per second (utitlity/benchmark.c).
// The code uses the Wiznet W5100S library for network communication.
// The code includes functions for initializing the hardware, handling network communication, and processing commands from the serial terminal.
// The code is designed to be modular and extensible, allowing for easy addition of new features and functionality.
// The code is also designed to be efficient and responsive, with low latency and high throughput.
// Note: checksum algorithm is used to ensure data integrity, and the code includes error handling for network communication. (timeout + jumpcode checksum)
// Note: The code is disables the terminal when the HAL driver connect to the io-samurai board, and enables when not running.

// -------------------------------------------
// Network Configuration
// -------------------------------------------
extern wiz_NetInfo default_net_info;
extern uint16_t port;
extern configuration_t *flash_config;
extern uint16_t adc_min;
extern uint16_t adc_max;
wiz_NetInfo net_info;

uint8_t rx_buffer[rx_size] = {0,};
uint8_t temp_tx_buffer[tx_size] = {0,};
uint8_t tx_buffer[tx_size] = {0,};
uint8_t counter = 0;
uint8_t first_send = 1;

#ifdef USE_SPI_DMA
static uint dma_tx;
static uint dma_rx;
static dma_channel_config dma_channel_config_tx;
static dma_channel_config dma_channel_config_rx;
#endif

uint8_t src_ip[4];
uint16_t src_port;

uint8_t checksum_error = 0;
uint8_t timeout_error = 0;
uint32_t last_time = 0;
static absolute_time_t last_packet_time;
uint32_t TIMEOUT_US = 100000;
uint32_t time_diff;


// -------------------------------------------
// Core 1 Entry Point (I2C, LCD, MCP23017, MCP23008)
// -------------------------------------------
void core1_entry() {
    int16_t result;
    uint8_t conf;
    bool MCP23008_present = false;
    bool MCP23017_present = false;
    float filtered_adc = 0.0f;
    bool first_sample = true;

    bool lcd = false;

    i2c_setup();
    sleep_ms(100);
    printf("Detecting SH1106 (OLED display) on %#x address\n", SH1106_ADDR);
    lcd = i2c_check_address(i2c1, SH1106_ADDR);
    if (lcd) {
        printf("SH1106 Init (OLED)\n");
        sh1106_init();    
    }
    else {
        printf("No SH1106 (OLED display) found on %#x address.\n", SH1106_ADDR);
    }

#ifdef MCP23008_ADDR
    printf("Detecting MCP23008 (Outputs) on %#x address\n", MCP23008_ADDR);
    if (i2c_check_address(i2c1, MCP23008_ADDR)) {
        MCP23008_present = true;
        printf("MCP23008 (Outputs) Init\n");
        mcp_write_register(MCP23008_ADDR, 0x00, 0x00);
    }
    else {
        printf("No MCP23008 (Outputs) found on %#x address.\n", MCP23008_ADDR);
    }

#endif

#ifdef MCP23017_ADDR
    printf("Detecting MCP23017 (Inputs) on %#x address\n", MCP23017_ADDR);
    if (i2c_check_address(i2c1, MCP23017_ADDR)) {
        MCP23017_present = true;
        printf("MCP23017 (Inputs) Init\n");
        mcp_write_register(MCP23017_ADDR, 0x00, 0xff);
        mcp_write_register(MCP23017_ADDR, 0x01, 0xff);
    }
    else {
        printf("No MCP23017 (Inputs) found on %#x address.\n", MCP23017_ADDR);
    }
#endif

    printf("Ready...\n");
    while (1) {
        gpio_put(LED_PIN, !timeout_error);

        if (time_diff > TIMEOUT_US) {
            checksum_index = 1;
            checksum_index_in = 1;
            timeout_error = 1;
            checksum_error = 0;
            src_ip[0] = 0;
        }
        else {
            timeout_error = 0;
        }

#ifdef MCP23008_ADDR
        if (checksum_error == 0 && timeout_error == 0) {
            mcp_write_register(MCP23008_ADDR, 0x09, rx_buffer[0]);
        }
        else
        {
            rx_buffer[0] = 0x00;
            mcp_write_register(MCP23008_ADDR, 0x09, 0x00);
        }
#endif

        result = scale_value(adc_read());
        float voltage = (float) result;

        if (rx_buffer[1] && 0x01){
            filtered_adc = low_pass_filter(voltage, filtered_adc, &first_sample);
        }
        else {
            filtered_adc = result;
        }
        

#ifdef MCP23017_ADDR
        memset(temp_tx_buffer, 0, sizeof(temp_tx_buffer));
        temp_tx_buffer[0] = mcp_read_register(MCP23017_ADDR, 0x13);
        temp_tx_buffer[1] = mcp_read_register(MCP23017_ADDR, 0x12);
        temp_tx_buffer[2] = (uint16_t)filtered_adc & 0xFF;
        temp_tx_buffer[3] = (uint16_t)filtered_adc >> 8;
        temp_tx_buffer[3] |= MCP23008_present ? 0x80 : 0x00;
        temp_tx_buffer[3] |= MCP23017_present ? 0x40 : 0x00;
        temp_tx_buffer[3] |= lcd ? 0x20 : 0x00;

#endif
        if (lcd){
            char txt_buff[16];
            sh1106_clear();
            draw_bytes(rx_buffer[0], 0, 0, 0); 
            draw_text("0123456789ABCDEF", 0, 9);
            draw_bytes(tx_buffer[0], tx_buffer[1], 0, 18); 
            sprintf(txt_buff, "ADC: %d", (uint16_t)filtered_adc);
            draw_text(txt_buff, 0, 32);
            if (checksum_error == 0){
                if (src_ip[0] != 0) {
                    sprintf(txt_buff, "%d.%d.%d.%d", src_ip[0], src_ip[1], src_ip[2], src_ip[3]);
                
                } else {
                    sprintf(txt_buff, "%d.%d.%d.%d", net_info.ip[0], net_info.ip[1], net_info.ip[2], net_info.ip[3]);
                }
                draw_text(txt_buff, 0, 44);
                if (timeout_error == 1) {
                    draw_text("Timeout error", 0, 54);
                }
            }
            else {
                draw_text("Checksum error", 0, 54);
            }
            if (checksum_error == 0 && timeout_error == 0) {
                sprintf(txt_buff, "Connected.");
                draw_text(txt_buff, 0, 54);
            }
            sh1106_update();
            }

        handle_serial_input();
        }
}

// -------------------------------------------
// (Core 0) UDP communication (DMA, SPI)
// -------------------------------------------
int main() {

    stdio_init_all();
    stdio_usb_init();
    gpio_init(LED_PIN);
    gpio_set_dir(LED_PIN, GPIO_OUT);
   
    sleep_ms(2000);


    printf("\033[2J");
    printf("\033[H");
    
    printf("\n\n--- IO-Samurai V1.0 ---\n");
    printf("Viola Zsolt 2025\n");
    printf("E-mail:atrex66@gmail.com\n");
    printf("\n");
    set_sys_clock_khz(125000, true);
    
    clock_configure(clk_peri,
                    0,
                    CLOCKS_CLK_PERI_CTRL_AUXSRC_VALUE_CLK_SYS,
                    clock_get_hz(clk_sys),
                    clock_get_hz(clk_sys));

    // SPI 40 MHz
    spi_init(spi0, 40000000);
    hw_write_masked(&spi_get_hw(spi0)->cr0, (0) << SPI_SSPCR0_SCR_LSB, SPI_SSPCR0_SCR_BITS); // SCR = 0
    hw_write_masked(&spi_get_hw(spi0)->cpsr, 4, SPI_SSPCPSR_CPSDVSR_BITS); // CPSDVSR = 4
    
    gpio_init(MCP_ALL_RESET);
    gpio_set_dir(MCP_ALL_RESET, GPIO_OUT);
    gpio_put(MCP_ALL_RESET, 0);
    sleep_ms(10);
    gpio_put(MCP_ALL_RESET, 1);

    gpio_init(MCP23017_INTA);
    gpio_init(MCP23017_INTB);
    gpio_set_dir(MCP23017_INTA, GPIO_IN);
    gpio_set_dir(MCP23017_INTB, GPIO_IN);
    gpio_pull_up(MCP23017_INTA);
    gpio_pull_up(MCP23017_INTB);

    w5100s_init();
    w5100s_interrupt_init();
    adc_init();
    adc_gpio_init(26);
    adc_select_input(0);
    load_configuration();
    network_init();
    multicore_launch_core1(core1_entry);
    handle_udp();
}

void reset_with_watchdog() {
    watchdog_enable(1, 1);
    while(1);
}

void __time_critical_func(cs_select)() {
    gpio_put(PIN_CS, 0);
    asm volatile("nop \n nop \n nop");
}

void __time_critical_func(cs_deselect)() {
    gpio_put(PIN_CS, 1);
}

uint8_t __time_critical_func(spi_read)() {
    uint8_t data;
    spi_read_blocking(SPI_PORT, 0x00, &data, 1);
    return data;
}

void __time_critical_func(spi_write)(uint8_t data) {
    spi_write_blocking(SPI_PORT, &data, 1);
}

int32_t __time_critical_func(_sendto)(uint8_t sn, uint8_t *buf, uint16_t len, uint8_t *addr, uint16_t port) {
    uint16_t freesize;
    uint32_t taddr;

    if (first_send) {
        setSn_DIPR(sn, addr);
        setSn_DPORT(sn, port);
        first_send = 0;
    }

    wiz_send_data(sn, buf, len);
    setSn_CR(sn, Sn_CR_SEND);
    while (getSn_CR(sn));

    while (1) {
        uint8_t tmp = getSn_IR(sn);
        if (tmp & Sn_IR_SENDOK) {
            setSn_IR(sn, Sn_IR_SENDOK);
            break;
        } else if (tmp & Sn_IR_TIMEOUT) {
            setSn_IR(sn, Sn_IR_TIMEOUT);
            return SOCKERR_TIMEOUT;
        }
    }
    return (int32_t)len;
}

int32_t __time_critical_func(_recvfrom)(uint8_t sn, uint8_t *buf, uint16_t len, uint8_t *addr, uint16_t *port) {
    uint8_t head[8];
    uint16_t pack_len = 0;

    while ((pack_len = getSn_RX_RSR(sn)) == 0) {
        if (getSn_SR(sn) == SOCK_CLOSED) return SOCKERR_SOCKCLOSED;
    }

    wiz_recv_data(sn, head, 8);
    setSn_CR(sn, Sn_CR_RECV);
    while (getSn_CR(sn));

    addr[0] = head[0];
    addr[1] = head[1];
    addr[2] = head[2];
    addr[3] = head[3];
    *port = (head[4] << 8) | head[5];
 
    uint16_t data_len = (head[6] << 8) | head[7];

    if (len < data_len) pack_len = len;
    else pack_len = data_len;

    wiz_recv_data(sn, buf, pack_len);
    setSn_CR(sn, Sn_CR_RECV);
    while (getSn_CR(sn));

    return (int32_t)pack_len;
}

void __time_critical_func(calculate_checksum)(uint8_t *data, uint8_t len) {
    uint8_t sum = 0;
    for (uint8_t i = 0; i < len; i++) {
        sum += data[i];
    }
    data[len] = sum;
}

void __time_critical_func(jump_table_checksum)() {
    if (checksum_error == 0) {
        checksum_index += (uint8_t)(rx_buffer[0] + rx_buffer[1] + 1);
        uint8_t checksum = jump_table[checksum_index];
        if (checksum != rx_buffer[2]) {
            checksum_error = 1;
        }
    }
}

void __time_critical_func(jump_table_checksum_in)() {
    checksum_index_in += (uint8_t)(tx_buffer[0] + tx_buffer[1] + tx_buffer[2] + tx_buffer[3] + 1);
    tx_buffer[4] = jump_table[checksum_index_in];
}


void __not_in_flash_func(core0_wait)(void) {
    while (!multicore_fifo_wready()) {
        tight_loop_contents();
    }
    multicore_fifo_push_blocking(0xFEEDFACE);
    printf("Core0 is ready to write...\n");
    uint32_t signal = multicore_fifo_pop_blocking();
    if (signal == 0xDEADBEEF) {
        watchdog_reboot(0, 0, 0);
    }
}


// -------------------------------------------
// UDP handler
// -------------------------------------------
void handle_udp() {
    while (1){
        while(gpio_get(IRQ_PIN) == 0)
        {
            if (multicore_fifo_rvalid()) {
                break;
            }
        }
        time_diff = absolute_time_diff_us(last_packet_time, get_absolute_time());
        if(getSn_RX_RSR(0) != 0) {
            counter++;
            int len = _recvfrom(0, rx_buffer, rx_size, src_ip, &src_port);
            if (len > 0) {
                jump_table_checksum();
                last_packet_time = get_absolute_time();
            }
            memcpy(tx_buffer, temp_tx_buffer, 5);
            jump_table_checksum_in();
            _sendto(0, tx_buffer, tx_size, src_ip, src_port);
        }

        if (multicore_fifo_rvalid()) {
        uint32_t signal = multicore_fifo_pop_blocking();
        printf("Core1 signal: %08X\n", signal);
        if (signal == 0xCAFEBABE) {
            core0_wait();
            }
        }

    }
}

void w5100s_interrupt_init() {
    gpio_init(INT_PIN);
    gpio_set_dir(INT_PIN, GPIO_IN);
    gpio_pull_up(INT_PIN);
    
    uint8_t imr = IMR_RECV;        
    uint8_t sn_imr = Sn_IMR_RECV;  
    
    setIMR(imr);
    setSn_IMR(SOCKET_DHCP, sn_imr);
}

// -------------------------------------------
// W5100S Init
// -------------------------------------------
void w5100s_init() {

    // GPIO init
    gpio_init(PIN_CS);
    gpio_set_dir(PIN_CS, GPIO_OUT);
    cs_deselect();

    gpio_init(PIN_RESET);
    gpio_set_dir(PIN_RESET, GPIO_OUT);
    gpio_put(PIN_RESET, 1);

    gpio_set_function(PIN_SCK, GPIO_FUNC_SPI);
    gpio_set_function(PIN_MOSI, GPIO_FUNC_SPI);
    gpio_set_function(PIN_MISO, GPIO_FUNC_SPI);
   
    reg_wizchip_cs_cbfunc(cs_select, cs_deselect);
    reg_wizchip_spi_cbfunc(spi_read, spi_write);
    
    #if USE_SPI_DMA
        reg_wizchip_spiburst_cbfunc(wizchip_read_burst, wizchip_write_burst);
    #endif

    gpio_put(PIN_RESET, 0);
    sleep_ms(100);
    gpio_put(PIN_RESET, 1);
    sleep_ms(500);

#ifdef USE_SPI_DMA
    dma_tx = dma_claim_unused_channel(true);
    dma_rx = dma_claim_unused_channel(true);

    dma_channel_config_tx = dma_channel_get_default_config(dma_tx);
    channel_config_set_transfer_data_size(&dma_channel_config_tx, DMA_SIZE_8);
    channel_config_set_dreq(&dma_channel_config_tx, DREQ_SPI0_TX);

    dma_channel_config_rx = dma_channel_get_default_config(dma_rx);
    channel_config_set_transfer_data_size(&dma_channel_config_rx, DMA_SIZE_8);
    channel_config_set_dreq(&dma_channel_config_rx, DREQ_SPI0_RX);
    channel_config_set_read_increment(&dma_channel_config_rx, false);
    channel_config_set_write_increment(&dma_channel_config_rx, true);
#endif

}

// -------------------------------------------
// Network Init
// -------------------------------------------
void network_init() {
    wiz_PhyConf phyconf;

    wizchip_init(0, 0);
    wizchip_setnetinfo(&net_info);

    setSn_CR(0, Sn_CR_CLOSE);
    setSn_CR(0, Sn_CR_OPEN);
    uint8_t sock_num = 0;
    socket(sock_num, Sn_MR_UDP, port, 0);

    printf("Network Init Done\n");
    wizchip_getnetinfo(&net_info);
    wizphy_getphyconf(&phyconf);
    printf("**************Network Info read from W5100S\n");
    printf("MAC: %02X:%02X:%02X:%02X:%02X:%02X\n", net_info.mac[0], net_info.mac[1], net_info.mac[2], net_info.mac[3], net_info.mac[4], net_info.mac[5]);
    printf("IP: %d.%d.%d.%d\n", net_info.ip[0], net_info.ip[1], net_info.ip[2], net_info.ip[3]);
    printf("Subnet: %d.%d.%d.%d\n", net_info.sn[0], net_info.sn[1], net_info.sn[2], net_info.sn[3]);
    printf("Gateway: %d.%d.%d.%d\n", net_info.gw[0], net_info.gw[1], net_info.gw[2], net_info.gw[3]);
    printf("DNS: %d.%d.%d.%d\n", net_info.dns[0], net_info.dns[1], net_info.dns[2], net_info.dns[3]);
    printf("DHCP: %d   (1-Static, 2-Dinamic)\n", net_info.dhcp);
    printf("PORT: %d\n", port);
    printf("*******************PHY status**************\n");
    printf("PHY Duplex: %s\n", phyconf.duplex == PHY_DUPLEX_FULL ? "Full" : "Half");
    printf("PHY Speed: %s\n", phyconf.speed == PHY_SPEED_100 ? "100Mbps" : "10Mbps");
    printf("*******************************************\n");
    }

#ifdef USE_SPI_DMA
static void wizchip_read_burst(uint8_t *pBuf, uint16_t len)
{
    uint8_t dummy_data = 0xFF;

    channel_config_set_read_increment(&dma_channel_config_tx, false);
    channel_config_set_write_increment(&dma_channel_config_tx, false);
    dma_channel_configure(dma_tx, &dma_channel_config_tx,
                          &spi_get_hw(SPI_PORT)->dr,
                          &dummy_data,              
                          len,                      
                          false);                   

    channel_config_set_read_increment(&dma_channel_config_rx, false);
    channel_config_set_write_increment(&dma_channel_config_rx, true);
    dma_channel_configure(dma_rx, &dma_channel_config_rx,
                          pBuf,                     
                          &spi_get_hw(SPI_PORT)->dr,
                          len,                      
                          false);                   

    dma_start_channel_mask((1u << dma_tx) | (1u << dma_rx));
    dma_channel_wait_for_finish_blocking(dma_rx);
}

static void wizchip_write_burst(uint8_t *pBuf, uint16_t len)
{
    uint8_t dummy_data;

    channel_config_set_read_increment(&dma_channel_config_tx, true);
    channel_config_set_write_increment(&dma_channel_config_tx, false);
    dma_channel_configure(dma_tx, &dma_channel_config_tx,
                          &spi_get_hw(SPI_PORT)->dr,
                          pBuf,                     
                          len,                      
                          false);                   

    channel_config_set_read_increment(&dma_channel_config_rx, false);
    channel_config_set_write_increment(&dma_channel_config_rx, false);
    dma_channel_configure(dma_rx, &dma_channel_config_rx,
                          &dummy_data,              
                          &spi_get_hw(SPI_PORT)->dr,
                          len,                      
                          false);                   

    dma_start_channel_mask((1u << dma_tx) | (1u << dma_rx));
    dma_channel_wait_for_finish_blocking(dma_rx);
}
#endif

void i2c_setup(void) {
    i2c_init(i2c1, 400 * 1000); // 400 kHz
    gpio_set_function(MCP_ALL_I2C_SDA, GPIO_FUNC_I2C);
    gpio_set_function(MCP_ALL_I2C_SCK, GPIO_FUNC_I2C);
    gpio_pull_up(MCP_ALL_I2C_SDA);
    gpio_pull_up(MCP_ALL_I2C_SCK);
}

uint8_t mcp_read_register(uint8_t i2c_addr, uint8_t reg) {
    uint8_t data;
    int ret;
    ret = i2c_write_blocking(i2c1, i2c_addr, &reg, 1, true);
    if (ret < 0) return 0xFF;
    ret = i2c_read_blocking(i2c1, i2c_addr, &data, 1, false);
    if (ret < 0) return 0xFF;
    return data;
}

void mcp_write_register(uint8_t i2c_addr, uint8_t reg, uint8_t value) {
    uint8_t data[2] = {reg, value};
    int ret = i2c_write_blocking(i2c1, i2c_addr, data, 2, false);
    if (ret < 0) {
        printf("I2C write failed %02X\n", i2c_addr);
        asm("nop");
    }
}

bool i2c_check_address(i2c_inst_t *i2c, uint8_t addr) {
    uint8_t buffer[1] = {0x00};
    int ret = i2c_write_blocking_until(i2c, addr, buffer, 1, false, make_timeout_time_us(1000));
    if (ret != PICO_ERROR_GENERIC) {
        return true;
    } else {
        return false;
    }
}

// Low-pass filter function (EMA)
float low_pass_filter(float new_sample, float previous_filtered, bool *first_sample) {
    if (*first_sample) {
        *first_sample = false;
        return new_sample; // Initialize with first sample
    }
    return ALPHA * new_sample + (1.0f - ALPHA) * previous_filtered;
}

typedef struct {
    float min;
    float max;
} minmax_t;

float scale_value(uint16_t xt) {
    minmax_t x;
    minmax_t y;

    y.min = 0.0f;
    y.max = 4095.0f;
    x.min = (float)adc_min;
    x.max = (float)adc_max;

    return (((float)xt - x.min) / (x.max - x.min)) * (y.max - y.min) + y.min;
}

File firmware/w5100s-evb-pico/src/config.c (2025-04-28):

#include <stdint.h>
#include <stdio.h>
#include <stdlib.h>
#include "wizchip_conf.h" // W5100S/W5500 könyvtárból
#include "hardware/flash.h"
#include "pico/flash.h"
#include "hardware/watchdog.h"
#include "pico/multicore.h"
#include "hardware/i2c.h"
#include "pico/stdlib.h"
#include "pico/sync.h"
#include "wizchip_conf.h"
#include <string.h>
#include <stdio.h>
#include "main.h"
#include "config.h"

extern void reset_with_watchdog();

configuration_t default_config = {
    .mac = {0x00, 0x08, 0xDC, 0x12, 0x34, 0x56},
    .ip = {192, 168, 0, 177},
    .sn = {255, 255, 255, 0},
    .gw = {192, 168, 0, 1},
    .dns = {8, 8, 8, 8},
    .dhcp = 1,
    .port = 8888,
    .timeout = 100000,
    .adc_min = 0,
    .adc_max = 4095
};

uint16_t port = 0;
int16_t adc_offset = 0;
uint16_t adc_min = 0;
uint16_t adc_max = 0;
configuration_t *flash_config = NULL;

#define FLASH_TARGET_OFFSET (1024 * 1024) // 1mb offset
#define FLASH_DATA_SIZE (sizeof(configuration_t))


void __time_critical_func(save_config_to_flash)() {
    if (flash_config == NULL) {
        printf("Nothing to save flash_config is empty.\n");
    }
    uint8_t *data;
    data = (uint8_t *)malloc(FLASH_SECTOR_SIZE);
    if (data == NULL) {
        printf("Failed to allocate memory for flash data.\n");
        return;
    }
    
    uint core_id = get_core_num();

    if (core_id == 1)
    {
        while (!multicore_fifo_wready()) {
            tight_loop_contents();
        }
        multicore_fifo_push_blocking(0xCAFEBABE);

        while(!multicore_fifo_rvalid()) {
            tight_loop_contents();
        }
        uint32_t signal = multicore_fifo_pop_blocking();
        if (signal != 0xFEEDFACE) {
            printf("Core0 is not ready, aborting flash write...\n");
            free(data);
            return;
        }
        printf("Core0 is ready, proceeding with flash write...\n");
    }

    memset(data, 0xFF, FLASH_SECTOR_SIZE);
    memcpy(data, flash_config, FLASH_SECTOR_SIZE);
    uint32_t ints = save_and_disable_interrupts();
    flash_safe_execute_core_deinit();
    flash_range_erase(FLASH_TARGET_OFFSET, FLASH_SECTOR_SIZE);
    flash_range_program(FLASH_TARGET_OFFSET, data, FLASH_SECTOR_SIZE);
    restore_interrupts(ints);
    free(data);
    if (core_id == 1){
    multicore_fifo_push_blocking(0xDEADBEEF);
    while (1) {
        tight_loop_contents();
        }
    }    
}

void load_config_from_flash() {
    if (flash_config == NULL) {
        flash_config = (configuration_t *)malloc(sizeof(configuration_t) + 1);
    }
    memcpy(flash_config, (configuration_t *)(XIP_BASE + FLASH_TARGET_OFFSET), sizeof(configuration_t));
    if (flash_config->dhcp < 1 || flash_config->dhcp > 2) {
        printf("Invalid DHCP mode restore config.\n");
        for (int i = 0; i < sizeof(configuration_t); i++) {
            printf(" %02X", ((uint8_t *)flash_config)[i]);
        }
        printf("\n");
        restore_default_config();
        save_config_to_flash();
    }
}

void restore_default_config() {
    if (flash_config == NULL) {
        flash_config = (configuration_t *)malloc(sizeof(configuration_t));
    }
    memcpy(flash_config, &default_config, sizeof(configuration_t));
    save_config_to_flash();
}

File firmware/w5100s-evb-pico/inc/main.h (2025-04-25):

#ifndef MAIN_H
#define MAIN_H

// -------------------------------------------
// Hardware Defines (Módosítsd a pinjeidnek megfelelően!)
// -------------------------------------------
#define SPI_PORT        spi0
#define PIN_MISO        16
#define PIN_CS          17
#define PIN_SCK         18
#define PIN_MOSI        19
#define PIN_RESET       20

#define MCP_ALL_RESET   14
#define MCP_ALL_I2C_SDA 2
#define MCP_ALL_I2C_SCK 3
#define MCP23017_INTA   6
#define MCP23017_INTB   7

#define IODIR           0x00
#define GPIO            0x09

#define MCP23017_ADDR   0x21
#define MCP23008_ADDR   0x20

#define USE_SPI_DMA     1

#define IRQ_PIN         21
#define LED_PIN         PICO_DEFAULT_LED_PIN

#define IMR_RECV      0x04
#define Sn_IMR_RECV   0x04
#define Sn_IR_RECV    0x04
#define SOCKET_DHCP   0

#define rx_size       3
#define tx_size       5

// Interrupt konfiguráció
#define INT_PIN 21
#define core1_running 1
// Low-pass filter parameters
#define ALPHA 0.25f // Smoothing factor (0.0 to 1.0, lower = more smoothing)

// -------------------------------------------
// Globális változók a magok közötti kommunikációhoz
// -------------------------------------------
// Függvény deklarációk
void jump_table_checksum();
void jump_table_checksum_in();
void i2c_setup(void);
uint8_t mcp_read_register(uint8_t i2c_addr, uint8_t reg);
void mcp_write_register(uint8_t i2c_addr, uint8_t reg, uint8_t value);
void cs_select();
void cs_deselect();
uint8_t spi_read();
void reset_with_watchdog();
void spi_write(uint8_t data);
int32_t _sendto(uint8_t sn, uint8_t *buf, uint16_t len, uint8_t *addr, uint16_t port);
int32_t _recvfrom(uint8_t sn, uint8_t *buf, uint16_t len, uint8_t *addr, uint16_t *port);
void handle_udp();
void w5100s_interrupt_init();
void w5100s_init();
void network_init();
void calculate_checksum(uint8_t *data, uint8_t len);
uint8_t xor_checksum(const uint8_t *data, uint8_t len);
void core1_entry();
bool i2c_check_address(i2c_inst_t *i2c, uint8_t addr);
float low_pass_filter(float new_sample, float previous_filtered, bool *first_sample);
uint16_t adc_scale(uint16_t adc_in);
float scale_value(uint16_t x);

#if USE_SPI_DMA
static void wizchip_write_burst(uint8_t *pBuf, uint16_t len);
static void wizchip_read_burst(uint8_t *pBuf, uint16_t len);
#endif

#endif // MAIN_H

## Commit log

2025-04-17 Initial commit with io-samurai project files
    [io-samurai.hal, io-samurai.kicad_pcb, io-samurai.kicad_sch]
2025-04-17 Update pinout.md with power requirements
2025-04-17 Update README.md with power requirements
2025-04-17 Changes to be committed: deleted: hardware/#auto_saved_files# deleted: hardware/fp-info-cache deleted: hardware/io-samurai-backups/io-samurai-2025-04-17_132557.zip deleted: hardware/io-samurai-backup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
2025-04-17 Hardware directory simplify
    [io-samurai.kicad_pcb, io-samurai.kicad_sch]
2025-04-17 hardware files for production added
    [io-samurai.kicad_pcb_bom.csv, io-samurai.kicad_pcb_positions.csv]
2025-04-17 hal file fix
    [io-samurai.hal]
2025-04-17 pico dir renamed to match hardware
2025-04-18 analog input added to pico and the hal driver
2025-04-18 Hal user guiide sample modified
2025-04-19 switchable low pass filter added
2025-04-19 tuning of python driver
2025-04-19 further supported boards
2025-04-19 added lowpass filter switch for analog
2025-04-19 oled panel power changed to 3.3v
2025-04-20 adding debug configuration for swd debugging
    [pico_debug.cfg]
2025-04-21 checksum error cleared when timeout
    [main.c]
2025-04-22 changed some features to reflect the project current state
2025-04-22 network configuration error fixed multiple io-samurai on the same network now working
    [config.c, main.c, main.h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]
2025-04-23 fixed multiple instances shared memory variables
    [io-samurai.c]
2025-04-24 terminal config fixed and finished added bits to the transfer for hardware present detection
    [config.c, main.c, serial_terminal.c]
2025-04-24 added picture of the new v1.0 industrial pcb (3d model)
2025-04-25 Multicore flash write fixed, using fifo to send command to core0 to wait for flash write
    [config.c, main.c, main.h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]
2025-04-28 nonrealtime cpp driver
2025-04-29 Added w5100s-ewb-pico link
2025-04-29 Added schematic in pdf
2025-05-16 fixed wrong variable set code
    [io-samurai.c]
2025-06-04 changed the trace of the w5500 module
